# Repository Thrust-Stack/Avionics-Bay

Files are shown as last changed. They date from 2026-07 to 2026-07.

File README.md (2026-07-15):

# Avionics-Bay

Avionics bay for the **Thrust-Stack Tilt & Roll Control** high power model rocket:
an active canard-based **roll control** system, its sensor/telemetry stack, and
the airframe CAD.

> **Read this first — repository layout is unusual.**
> The `main` branch (which you are reading) currently contains **only the
> mechanical CAD** (`Tilt & Roll Control Project/`) and this README. **None of
> the firmware or control software is on `main`.** It lives on separate feature
> branches:
>
> | Branch | Contents |
> |--------|----------|
> | [`Controls`](../../tree/Controls) | Most complete software set — ESP32 firmware, roll-control laws, GPS/telemetry logging, LoRa telemetry, wiring reference |
> | [`Raspi`](../../tree/Raspi) | Raspberry Pi 5 camera capture + a copy of the control/GPS programs |
> | [`Meshtastic-Programs`](../../tree/Meshtastic-Programs) | Meshtastic serial send/receive experiments + wiring reference |
>
> File paths and code excerpts below are taken from the **`Controls`** branch
> unless noted. Nothing here has been merged into `main`.

---

## Table of Contents

1. [Project Overview](#1-project-overview)
2. [Hardware Architecture](#2-hardware-architecture)
   - [2.1 Components](#21-components)
   - [2.2 Buses and Wiring](#22-buses-and-wiring)
   - [2.3 Power System](#23-power-system)
   - [2.4 Wiring Diagram / Schematic (placeholder)](#24-wiring-diagram--schematic-placeholder)
   - [2.5 Documentation vs. firmware discrepancies](#25-documentation-vs-firmware-discrepancies)
3. [Software Architecture](#3-software-architecture)
   - [3.1 Data path](#31-data-path)
   - [3.2 Firmware / module reference](#32-firmware--module-reference)
   - [3.3 Control loop](#33-control-loop)
   - [3.4 Arming / safety state logic](#34-arming--safety-state-logic)
4. [Build and Flash Instructions](#4-build-and-flash-instructions)
5. [Repository Structure](#5-repository-structure)
6. [Safety Notes](#6-safety-notes)
7. [Status / Known Limitations](#7-status--known-limitations)

---

## 1. Project Overview

This repository is the avionics bay and control system for an active
**tilt/roll control** high power model rocket built by Thrust-Stack, intended
to fly on an **AeroTech H219** motor. The airframe carries movable **canards**
whose deflection generates a roll moment; the goal of the avionics bay is to
**hold the airframe near zero roll rate during boost and coast**, rather than
letting the rocket spin up on its own. On-board sensors measure angular rate,
acceleration, barometric altitude, and GPS position; a control law converts
roll-rate error into a commanded canard deflection.

> **What is actually implemented vs. the project name.** The folder is named
> *Tilt & Roll Control*, and the CAD includes both static fins and movable
> canards, but the **firmware and control laws in this repo implement roll
> control only** — a single signed deflection applied to two mirrored canards.
> Tilt (pitch/yaw) is *estimated* from the accelerometer and used as an input
> to the ground-test controller, but there is no thrust-vectoring or 4-axis fin
> control in the flashed firmware. See [§7](#7-status--known-limitations).
>
> The AeroTech H219 is the project's stated flight motor; the repository itself
> contains **no motor data or thrust curve** (the CAD `Fake Motor` parts are
> inert mass/fit models used for CFD and assembly, not the real motor).

---

## 2. Hardware Architecture

The wiring below reflects the **current physical harness** (I²C on GPIO 23/32,
direct-PWM canard servos, and a wired ESP32 ↔ Raspberry Pi 5 UART link). Where
older firmware or the historical branch wiring reference disagrees with this
harness, the conflict is called out in
[§2.5](#25-documentation-vs-firmware-discrepancies) — reconcile against the
sketch actually flashed before flight.

### 2.1 Components

| Role | Part | Interface | Address / pins / rate |
|---|---|---|---|
| Flight MCU / sensor bridge | **ESP32**, board `NodeMCU-32S` | — | USB serial @ **115200** to host |
| IMU (accel + gyro) | **MPU6050** (Adafruit driver) | I²C (SDA GPIO23 / SCL GPIO32) | **AD0 → GND** (nominal `0x68`) ¹; ±16 g accel, ±500 °/s gyro, 21 Hz DLPF; sampled @ **20 Hz** |
| Barometric altimeter | **BMP585** (Adafruit `BMP5xx`) | I²C (SDA GPIO23 / SCL GPIO32) | `BMP5XX_DEFAULT_ADDRESS` (**`0x46`** per code comment) ¹; 4× pressure OSR, IIR coeff 3; sampled @ **10 Hz** |
| GPS | **Adafruit Ultimate GPS V3** | UART (ESP32 `Serial2`) | **9600** baud, NMEA; GPS TX → GPIO16, GPS RX → GPIO17; powered from ESP32 3V3 |
| Roll actuators | **2 × canard servos** (wiring ref names *BMS-127WV+*) | Direct ESP32 PWM | **Canard 1 → GPIO26, Canard 2 → GPIO25**; neutral 90°; ±15° max deflection |
| Onboard computer | **Raspberry Pi 5** | UART to ESP32 | Pi GPIO14 (TX) → ESP32 **GPIO27** (RX); Pi GPIO15 (RX) ← ESP32 **GPIO33** (TX); common GND required |
| Telemetry radio (optional) | **Heltec WiFi LoRa 32 V4** (Semtech **SX1262**) | SPI + LoRa | 915 MHz, SF7, BW 125 kHz, CR 4/5, +14 dBm, 2 Hz |
| Ground station | Laptop running the Python stack | USB serial + UDP | — |

¹ With AD0 physically tied to GND the MPU6050 should respond at `0x68`, but the
`Controls`-branch firmware historically defined `MPU6050_ADDR = 0x69` with the
comment *"AD0 reads high on this board despite being wired to GND."* The old
wiring reference also listed the BMP585 at `0x47` in places. Confirm both
addresses with an I²C scanner on the current harness before flight.

> **PCA9685 removed from the harness.** Earlier revisions drove the canards
> through a PCA9685 16-channel PWM driver (I²C `0x40`, channels 12/13). The
> current wiring drives both servos **directly from ESP32 GPIO 25/26** and the
> PCA9685 is no longer part of the signal chain. If the flashed sketch still
> initializes a PCA9685, it does not match this harness — see
> [§2.5](#25-documentation-vs-firmware-discrepancies).

### 2.2 Buses and Wiring

Current harness, ESP32 as the hub:

```text
BMP585 ──┐
          ├── I²C (SDA GPIO23 / SCL GPIO32) ──► ESP32 ──USB serial 115200──► Laptop
MPU6050 ─┘   (MPU AD0 → GND)                     │
                                                  ├── UART2 (RX GPIO16 ◄─ GPS TX,
                                                  │          TX GPIO17 ─► GPS RX, 9600)
                                                  ├── GPIO26 ─► Canard 1 servo PWM
                                                  ├── GPIO25 ─► Canard 2 servo PWM
                                                  └── UART (RX GPIO27 ◄─ Pi GPIO14 TX,
                                                            TX GPIO33 ─► Pi GPIO15 RX)
                                                                 Raspberry Pi 5
                                                            (common GND with ESP32)
```

Pin-by-pin:

| Signal | From | To |
|---|---|-----|
| GPS VIN | ESP32 **3V3** | GPS VIN |
| GPS GND | ESP32 GND | GPS GND |
| GPS TX | GPS | ESP32 **GPIO16** (Serial2 RX) |
| GPS RX | GPS | ESP32 **GPIO17** (Serial2 TX) |
| I²C SDA (shared) | MPU6050 + BMP585 SDA | ESP32 **GPIO23** |
| I²C SCL (shared) | MPU6050 + BMP585 SCL | ESP32 **GPIO32** |
| MPU6050 AD0 | MPU6050 | ESP32 GND |
| Canard 1 servo PWM | ESP32 **GPIO26** | Servo 1 signal |
| Canard 2 servo PWM | ESP32 **GPIO25** | Servo 2 signal |
| Pi TX → ESP32 RX | Pi **GPIO14** | ESP32 **GPIO27** |
| Pi RX ← ESP32 TX | Pi **GPIO15** | ESP32 **GPIO33** |
| Pi GND | Pi | ESP32 GND (**common ground required**) |

- **I²C bus (shared):** MPU6050 and BMP585 share `SDA = GPIO23`,
  `SCL = GPIO32`, with unique addresses.
- **GPS:** UART on `Serial2` (GPIO16/17), 9600 baud; raw NMEA is forwarded to
  the host.
- **Actuators:** the two mirrored canards are driven by **direct ESP32 PWM** on
  GPIO26 (canard 1) and GPIO25 (canard 2). No external PWM driver.
- **Pi 5 link:** a dedicated UART now physically connects the ESP32
  (GPIO27 RX / GPIO33 TX) to the Pi's GPIO14/15, with grounds commoned. Verify
  which sketch/host program actually uses this link — the `Controls`-branch
  bridge historically streamed over **USB serial to a laptop**
  ([§2.5](#25-documentation-vs-firmware-discrepancies)).
- **Telemetry radio (separate board):** The Heltec V4 pinout is SPI
  (`SCK 9 / MISO 11 / MOSI 10 / NSS 8`), `DIO1 14`, `RST 12`, `BUSY 13`, plus
  RF front-end enable on `GPIO2`. It is an independent link, not wired into the
  ESP32 sensor bridge.

### 2.3 Power System

| Component | Voltage | Source |
|---|---|---|
| ESP32 | 5 V | USB or 5 V regulator |
| Raspberry Pi 5 | 5 V | USB-C PD or 5V-5A battery |
| GPS V3 / BMP585 / MPU6050 | 3.3 V | ESP32 `3V3` pin |
| Canard servos | 7.4 V 2S LiPo with a 2200 μF bulk cap — *the wiring reference also mentions a 5 V BEC; reconcile before flight* | Dedicated rail, **never** the ESP32 |

- Sensors and the GPS run off the ESP32's onboard 3.3 V regulator (AMS1117).
  Note this regulator has limited headroom with GPS + BMP585 + MPU6050 all on
  the 3V3 pin; watch for brownouts under load and consider a dedicated 3.3 V
  buck for the sensor rail.
- Servos must be powered from a **dedicated rail** (a 5 V BEC rated ≥5 A per the
  doc, 8–10 A recommended; or a 7.4 V 2S LiPo). The wiring reference is
  internally inconsistent about which — verify your servo voltage rating (2S is
  8.4 V fully charged) before connecting.
- **All grounds must be common:** ESP32, servo power rail, sensors, GPS, and Pi.
  The Pi ↔ ESP32 ground link is explicitly part of the harness (see §2.2).

### 2.4 Wiring Diagram / Schematic (placeholder)

> **No schematic or wiring image exists in the repository yet.** The pin table
> in §2.2 above is the current authoritative connection list. A proper
> KiCad/schematic capture or a labeled wiring photo should be added here:
>
> ```
> docs/wiring-diagram.png   <-- TODO: add schematic / harness diagram
> ```

### 2.5 Documentation vs. firmware discrepancies

The harness in §2.2 is the **current physical wiring**. The `Controls`-branch
firmware and the older branch wiring reference were written against earlier
revisions and may not match it. **Verify the flashed sketch against this table
before flight:**

| Topic | Current harness (§2.2) | Older firmware / wiring reference |
|---|---|---|
| I²C pins | SDA **GPIO23** / SCL **GPIO32** | Firmware: `Wire.begin(21, 22)` |
| Actuators | **2 canards, direct ESP32 PWM** on GPIO26 (canard 1) / GPIO25 (canard 2) | Firmware: 2 canards via **PCA9685** (I²C `0x40`) ch 12/13 @ 50 Hz; old wiring ref: 4 servos on GPIO 13/14/25/26 @ 250 Hz |
| PCA9685 | **Not in the harness** | Firmware initializes it; old wiring ref maps servos to ch 0–3 in one section, ch 12/13 in the firmware |
| MPU6050 address | AD0 → GND (nominal **`0x68`**) | Firmware: `0x69` (comment: "AD0 reads high on this board despite being wired to GND") — rescan on the current board |
| BMP585 address | `0x46` (code comment) | Old wiring ref: `0x47` in places; firmware error string separately mentions `0x47` |
| ESP32 ↔ Pi 5 UART | **Physically wired**: Pi GPIO14/15 ↔ ESP32 GPIO27/33, common GND | Firmware: link **not implemented** — the flashed bridge streams over USB serial to a laptop; old wiring ref described UART1 on GPIO 2/4 |

---

## 3. Software Architecture

### 3.1 Data path

The implemented system is a **hardware-in-the-loop link over USB + localhost
UDP**, not a self-contained onboard controller:

```text
[ESP32 bridge] --USB serial 115200--> [GPSReader.py]
      ^  ($IMU 20Hz, $ALT 10Hz, NMEA passthrough)   |
      |                                              | UDP 5761 (telemetry: $IMU/$ALT/$GPS)
      |                                              v
      |                                    [BasicRollControl.py  OR
      |                                     GroundRollControlTest.py]
      |                                              |
      +-------- serial <-- UDP 5760 (ROLL,<deg>) ----+
                (GPSReader relays UDP 5760 -> ESP32 serial)
```

- ESP32 emits `$IMU,ax,ay,az,gx,gy,gz` (accel m/s², **gyro rad/s** from the
  Adafruit driver) at 20 Hz, `$ALT,<agl_m>` (ground-zeroed barometric altitude)
  at 10 Hz, and passes GPS NMEA through unchanged.
- `GPSReader.py` logs everything to SQLite and re-broadcasts sensor packets on
  UDP `127.0.0.1:5761`. It relays inbound `ROLL,<deg>` commands from UDP
  `5760` straight to the ESP32 over the serial port it already holds.
- A controller listens on 5761, computes a deflection, and sends `ROLL,<deg>`
  to 5760. The ESP32 applies the same signed deflection to both canards.
- **Pi 5 UART:** the ESP32 ↔ Pi UART link (ESP32 GPIO27/33 ↔ Pi GPIO14/15) is
  now **physically wired** (§2.2), but the `Controls`-branch software path
  above still runs over USB serial to a laptop. Software support for the Pi
  link (on both the ESP32 sketch and a Pi-side reader) must be confirmed or
  added before it can replace the USB path.

### 3.2 Firmware / module reference

| File (branch) | Runs on | Responsibility |
|---|---|---|
| `Esp32 Programs/Esp32_sensor_bridge/Esp32_sensor_bridge.ino` (Controls) | ESP32 | Reads MPU6050 + BMP585 (I²C) and GPS (UART2); streams `$IMU`/`$ALT`/NMEA over USB; parses `ROLL,<deg>` and drives the canards. Zeroes ground pressure at boot (20-sample average). **Note:** the checked-in version drives the canards via PCA9685 and uses I²C on GPIO21/22 — it predates the direct-PWM / GPIO23-32 harness in §2.2. |
| `GPSReader.py` (Controls/Raspi) | Laptop | Auto-detects the ESP32 COM port; parses `$IMU`/`$ALT`/NMEA; logs to `logs/flight_*.db` (SQLite) and auto-exports `.xlsx`; UDP telemetry re-broadcast + command relay. |
| `Controls/Roll Control/BasicRollControl.py` (Controls) | Laptop | **Flight-intent** roll controller: Kalman-filtered roll rate, multi-sensor velocity fusion, velocity-scheduled gain, altitude/tilt/staleness safety gate. |
| `Controls/Roll Control/GroundRollControlTest.py` (Controls) | Laptop | **Bench/ground** controller: aggressive fixed gains, ±15° authority, roll-rate + tilt terms. Explicitly **bypasses altitude safety — not a flight controller.** |
| `export_to_excel.py` (Controls/Raspi) | Laptop | Converts a session `.db` into a formatted 3-sheet (GPS/IMU/ALT) Excel workbook. |
| `Communication/HeltecV4TelemetryTransmitter.ino` / `…Receiver.ino` (Controls) | 2× Heltec V4 | Point-to-point 20-byte LoRa telemetry (SX1262 via RadioLib) with CRC-16/CCITT and a packet counter for loss detection. **Transmitter payload is placeholder data** (`fillSensorData()` hardcodes example values). |
| `Communication/heltec_link_test.py` (Controls) | 2× laptops | tx/rx/compare link-quality test that reports delivered %, RSSI, SNR, and missing packet IDs. |
| `Communication/Sender.py` / `Reciever.py` (Controls/Meshtastic) | Laptop | Meshtastic serial send/receive experiments. `Sender.py` transmits **placeholder joke strings**, not telemetry. |
| `Camera/camera_capture.py` (Raspi) | Raspberry Pi 5 | Picamera2 H.264/MP4 video, periodic JPEGs, and full-res stills. Never raises on camera failure — isolated from the rest of the stack. |

### 3.3 Control loop

**`BasicRollControl.py` (flight-intent), ~100 Hz:**

1. Receive `$IMU`/`$ALT`/`$GPS` snapshots over UDP; convert gyro rad/s → deg/s.
2. Estimate roll rate with a scalar **Kalman filter** (`gyro_z` taken as roll
   axis).
3. Estimate vertical velocity with a **1-state Kalman velocity-fusion**
   estimator combining GPS vertical velocity, integrated accelerometer, and
   differentiated barometric altitude, with innovation gating.
4. **Gain scheduling:** below 0.1 m/s use nominal `KP`; above it, scale gain by
   `KP / (CANARD_ACCELERATION_COEFFICIENT · v²)` so control authority tracks
   dynamic pressure.
5. Command `fin = clamp(gain · (0 − roll_rate), ±7.5°)`, send `ROLL,<deg>`.
6. On exit / stale telemetry, command neutral (0°).

**`GroundRollControlTest.py` (bench), continuous:** fixed `ROLL_RATE_GAIN = 1.4`,
`TILT_GAIN = 2.0`, ±15° authority; `command = 1.4·roll_rate_error − 2.0·tilt_y`;
tilt estimated from the accelerometer (valid only for slow/ground motion).

**ESP32 `setCanards()`:** clamps to ±15°, applies the same signed deflection to
both canards around 90° neutral (plus per-canard trim constants, currently 0).
In the current harness the outputs are direct PWM on GPIO26/25 (§2.2); the
checked-in sketch still targets PCA9685 channels
([§2.5](#25-documentation-vs-firmware-discrepancies)).

### 3.4 Arming / safety state logic

There is **no hardware arm switch, insert-to-arm pin, or pyro interlock** in the
firmware. "Arming" is entirely **software gating** in the host controller:

- **`BasicRollControl.py`** runs a two-state machine:
  `CONTROL_ACTIVE` only when `control_is_allowed()` (altitude ≥ 0, |tilt_x| <
  90°, |tilt_y| < 90°) **and** telemetry is fresh (an IMU packet within 0.5 s);
  otherwise `IDLE` → **neutral command**. Loss of telemetry → neutral.
- **`GroundRollControlTest.py`** has only a freshness gate
  (`GROUND_TEST_ACTIVE` vs `STALE_TELEMETRY` → neutral) and **deliberately
  bypasses the altitude/tilt safety logic** — its own argparse help says *"do
  not use as flight controller."*
- **On the ESP32**, canards are parked at neutral (90°) at boot; the servos will
  physically move to neutral as soon as the board powers up.

---

## 4. Build and Flash Instructions

There is **no Makefile, PlatformIO project, or CMake** anywhere in the repo. The
firmware is Arduino sketches and the host code is plain Python scripts.

### 4.1 ESP32 sensor bridge (`Esp32_sensor_bridge.ino`)

- **Board:** `NodeMCU-32S` (ESP32) in the Arduino IDE / `arduino-cli`.
- **Libraries** (Library Manager, per the sketch header): Adafruit MPU6050,
  Adafruit BMP5xx, Adafruit Unified Sensor. (The Adafruit PWM Servo Driver
  Library was required by the PCA9685-era sketch; a direct-PWM build will use
  `ESP32Servo` or LEDC instead — match the sketch you flash.)
- Open `Esp32 Programs/Esp32_sensor_bridge/Esp32_sensor_bridge.ino`, select the
  board and port, and Upload.
- **Verify pins against §2.2 before flashing:** the checked-in sketch predates
  the current harness (I²C on 21/22, PCA9685 actuation). Update `Wire.begin()`
  to (23, 32) and the servo output path to direct PWM on GPIO26/25 — or rewire —
  before running the control loop.

### 4.2 Heltec V4 LoRa telemetry (`HeltecV4Telemetry*/…ino`)

- **Library:** RadioLib (Library Manager).
- Select the **exact Heltec WiFi LoRa 32 V4** board revision; attach the correct
  regional LoRa antenna **before powering** (there is a separate 2.4 GHz
  connector — do not confuse them).
- Flash the transmitter to the avionics board and the receiver to the ground
  board; open both serial monitors at 115200. For the transmitter's TX log lines
  over USB, compile with **USB CDC On Boot: Enabled**.

### 4.3 Host Python stack (laptop)

Dependencies are documented per-script; there is no single `requirements.txt`.
The only pinned file is `Communication/requirements-link-test.txt` (`pyserial`).

```bash
# GPS/telemetry logger + Excel export
pip install pyserial pynmea2 openpyxl
python GPSReader.py            # then, in another terminal:
python "Controls/Roll Control/BasicRollControl.py"       # or GroundRollControlTest.py
python export_to_excel.py     # convert the latest logs/*.db to .xlsx

# LoRa link-quality test (two computers)
py -m pip install -r Communication/requirements-link-test.txt
py Communication/heltec_link_test.py tx --port COM7 --duration 120 --output tx_report.json
py Communication/heltec_link_test.py rx --port COM9 --duration 120 --output rx_report.json
py Communication/heltec_link_test.py compare tx_report.json rx_report.json

# Meshtastic experiments
pip install meshtastic pypubsub
```

Use `--no-commands` on either controller to observe telemetry without moving
servos.

### 4.4 Raspberry Pi 5 camera (`camera_capture.py`, Raspi branch)

- **Picamera2 is installed via apt, not pip:** `sudo apt install -y
  python3-picamera2 ffmpeg`. If using a venv, create it with
  `--system-site-packages`.
- Verify with `rpicam-hello --list-cameras` (expect `imx708`), then:
  `python3 camera_capture.py --mode video --duration 30`.

---

## 5. Repository Structure

### `main` branch (this branch)

| Path | Purpose |
|---|---|
| `README.md` | This document. |
| `Tilt & Roll Control Project/` | SolidWorks CAD for the airframe and bay. |
| `Tilt & Roll Control Project/*.SLDPRT` | Parts: canards, airfoil fins, avionics bay plates (top/bottom), body tubes, nose cone, couplers, servo mount/attachment, bearings & mounts, camera mount, Pi Camera Module 3, fin jig, "fake" motor/bearing (fit models). |
| `Tilt & Roll Control Project/*.SLDASM` | Assemblies: `Rocket Assembly (1–3)`, `Camera + Mount`, `Static Fin + Lower Bearing Mount`. |
| `Tilt & Roll Control Project/CFD Model (3)/` | CFD variant of the assembly + a `.STEP` export. |

> `main` contains **no source code, build files, or wiring diagrams** — only CAD
> and this README.

### Software branches (not merged into `main`)

| Path (on `Controls` / `Raspi`) | Purpose |
|---|---|
| `Esp32 Programs/Esp32_sensor_bridge/` | ESP32 sensor-bridge + roll-actuation firmware. |
| `GPSReader.py`, `export_to_excel.py` | Host logger and Excel export. |
| `Controls/Roll Control/` | `BasicRollControl.py` (flight-intent), `GroundRollControlTest.py` (bench). |
| `Communication/` | Heltec LoRa sketches + `heltec_link_test.py` + `HELTEC_V4_TELEMETRY.md`; Meshtastic `Sender.py`/`Reciever.py`. |
| `Camera/` (Raspi) | `camera_capture.py` + camera README. |
| `logs/` | Captured session `.db`/`.xlsx` files. |
| `README.md` (branch) | Historical wiring reference — superseded by §2.2 of this document; see [§2.5](#25-documentation-vs-firmware-discrepancies) for its known conflicts. |

---

## 6. Safety Notes

> ⚠️ This is a **high power rocket**. Treat every step below as capable of
> causing injury or fire.

- **Motor / launch (AeroTech H219):** High power motors require appropriate
  certification (e.g., NAR/Tripoli), an approved launch site, and FAA/landowner
  compliance. The repository contains no ignition or launch-detect control code;
  **motor ignition is an external, irreversible action** — arm the igniter last,
  from a safe distance, per range rules.
- **Recovery / ejection charges are NOT handled by this repo.** There is no
  pyro, ejection-charge, or deployment code anywhere in the firmware. If the
  airframe uses ejection charges or a separate commercial flight computer for
  recovery, that system is **out of scope here** and must be armed and verified
  independently. Do not assume this avionics bay provides recovery.
- **Servos move on power-up.** The ESP32 drives both canards to neutral the
  instant it boots. **Keep hands and tools clear of the canards** whenever the
  bay is powered.
- **Never power the servos from the ESP32.** Use the dedicated servo rail (5 V
  BEC or 2S LiPo per the wiring reference). Verify servo voltage rating against a
  fully charged 2S (8.4 V) before connecting.
- **LiPo handling:** charge/store/transport per standard LiPo safety; a 2S servo
  pack at 8.4 V can source high current into a fault.
- **Ground testing:** `GroundRollControlTest.py` uses **aggressive gains and the
  full ±15° deflection and bypasses altitude safety.** Bench-test with the
  airframe restrained and clear of people; it is not a flight controller.
- **Verify pins and addresses before flight:** the checked-in firmware and the
  current harness disagree on I²C pins, actuator wiring, and possibly I²C
  addresses ([§2.5](#25-documentation-vs-firmware-discrepancies)). Confirm the
  MPU6050 and BMP585 with an I²C scanner on GPIO23/32 and sweep both servos on
  GPIO26/25 before installing the bay.

---

## 7. Status / Known Limitations

Grounded in the current code and comments:

- **Software is unmerged and split across branches.** `main` has no firmware;
  `Controls`, `Raspi`, and `Meshtastic-Programs` are not integrated with each
  other.
- **Roll only.** Despite the "Tilt & Roll" name and the 4-fin/canard CAD, only
  **2-canard roll control** is implemented. There is no thrust-vectoring or
  independent 4-fin control in firmware.
- **No flight validation in the repo.** The controllers are labeled "basic" and
  "ground test"; session logs exist under `logs/`, but there is **no evidence of
  a validated powered flight**, and no test report characterizing performance.
- **Checked-in firmware lags the current harness.** The harness now uses I²C on
  GPIO23/32, direct servo PWM on GPIO26/25 (no PCA9685), and a wired ESP32↔Pi
  UART (GPIO27/33 ↔ Pi GPIO14/15) — the `Controls`-branch sketch still
  initializes I²C on 21/22 and drives a PCA9685
  ([§2.5](#25-documentation-vs-firmware-discrepancies)). Update and re-verify
  before flight.
- **Pi 5 UART link is wired but its software path is unconfirmed.** The
  physical UART now exists (§2.2), but the checked-in bridge streams to a
  **laptop over USB**; ESP32-side and Pi-side software for the UART link must
  be confirmed or written.
- **LoRa telemetry sends placeholder data.** `HeltecV4TelemetryTransmitter.ino`'s
  `fillSensorData()` hardcodes example altitude/battery/temp/GPS values —
  *"Replace these example values with real sensor reads."* It is not yet wired to
  the sensor bridge.
- **Meshtastic scripts are experiments.** `Sender.py` transmits placeholder joke
  strings; `Reciever.py`'s `PORT` is unset (`"xxxx"`).
- **Uncalibrated actuator trims.** `CANARD1_TRIM` / `CANARD2_TRIM` are `0.0`
  with a "tune until neutral" comment.
- **Gyro-unit assumptions.** Comments disagree on whether gyro is logged in
  rad/s or deg/s; the controllers default to `rad/s` and assume `gyro_z` is the
  roll axis for the current wiring. Confirm on hardware.
- **No build system / no schematic image.** Arduino sketches + loose Python
  scripts; no Makefile/PlatformIO; no wiring diagram or schematic file.

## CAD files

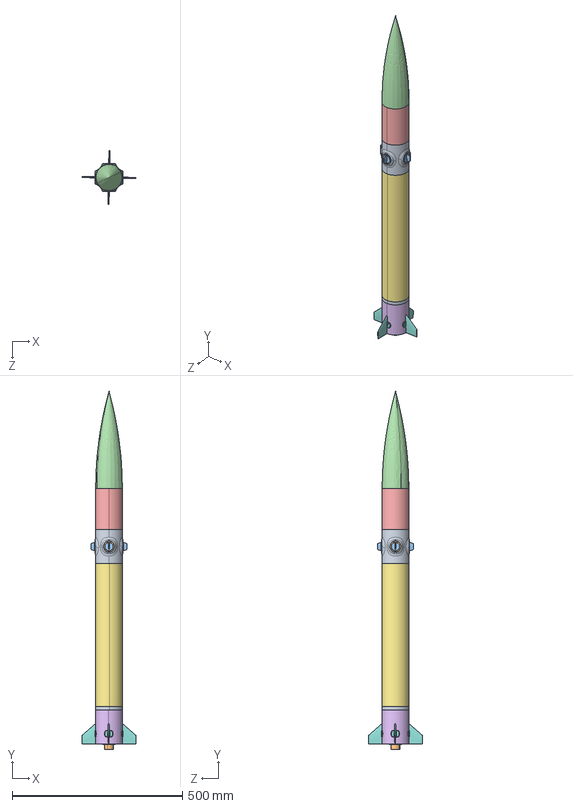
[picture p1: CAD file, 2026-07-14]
Tilt & Roll Control Project/CFD Model (3)/Rocket Assembly (3) (CFD).STEP
158.6 x 1052.1 x 158.6 mm
Servo Fin Can (3) (CFD)
Small Bearing (3) (CFD) x 4
Airfoil Canard (4) (CFD) x 4
Nose Cone (CFD)
Upper Body Tube (3) (CFD)
Static Fin Can (3) (CFD)
Lower Body Tube (3) (CFD)
Airfoil Fin (CFD) x 4
Lower Bearing Mount (2) (CFD)
Fake Motor (CFD)

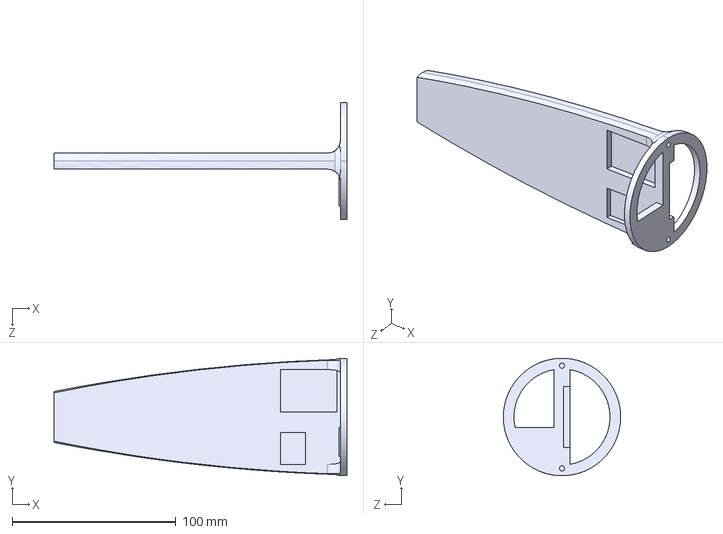
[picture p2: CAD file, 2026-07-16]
Tilt & Roll Control Project/26.07.10 Avionics Bay Plate (Top Half).STEP
178.7 x 71.6 x 71.6 mm

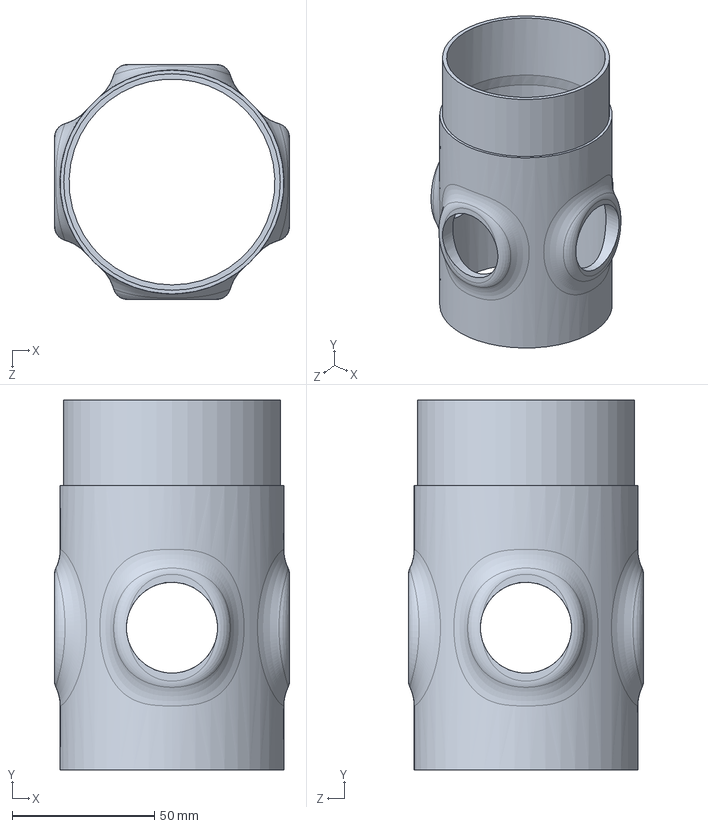
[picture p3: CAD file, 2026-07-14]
Tilt & Roll Control Project/CFD Model (3)/Servo Fin Can (3) (CFD).SLDPRT
82.6 x 130.0 x 82.6 mm

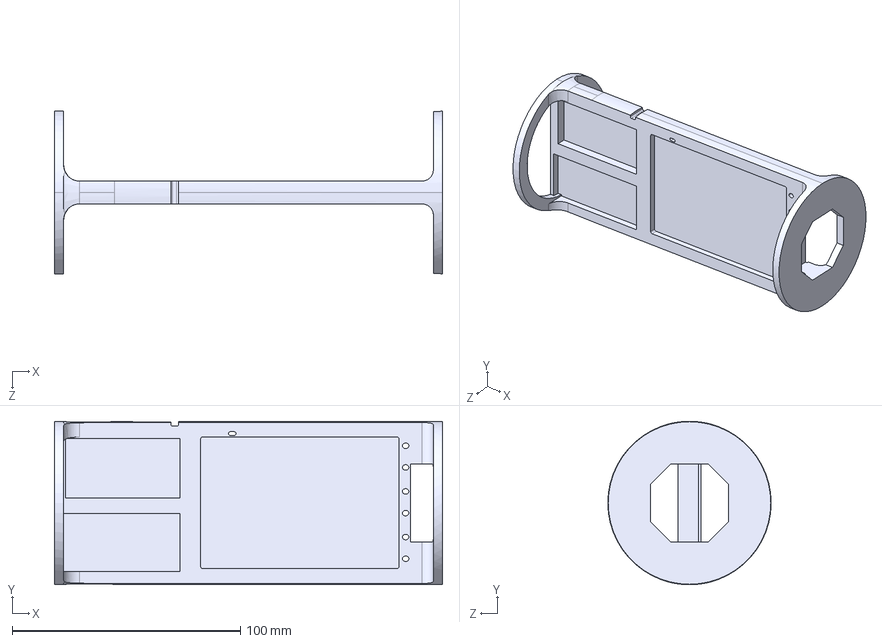
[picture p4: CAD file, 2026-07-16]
Tilt & Roll Control Project/26.07.13 Avionics Bay Plate (Bottom Half).STEP
170.0 x 71.6 x 71.6 mm

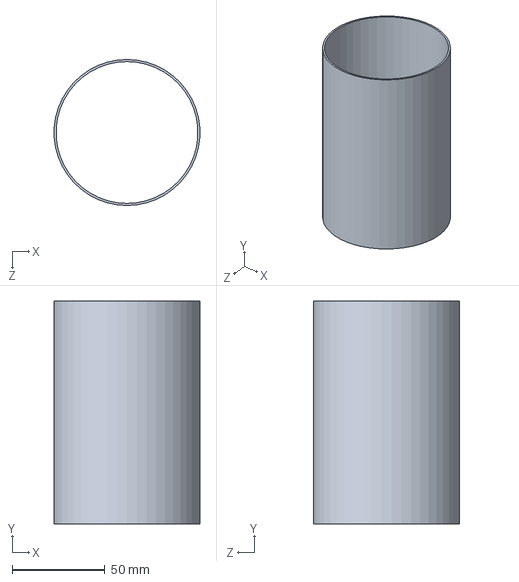
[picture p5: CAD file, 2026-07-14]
Tilt & Roll Control Project/CFD Model (3)/Upper Body Tube (3) (CFD).SLDPRT
78.4 x 120.0 x 78.6 mm

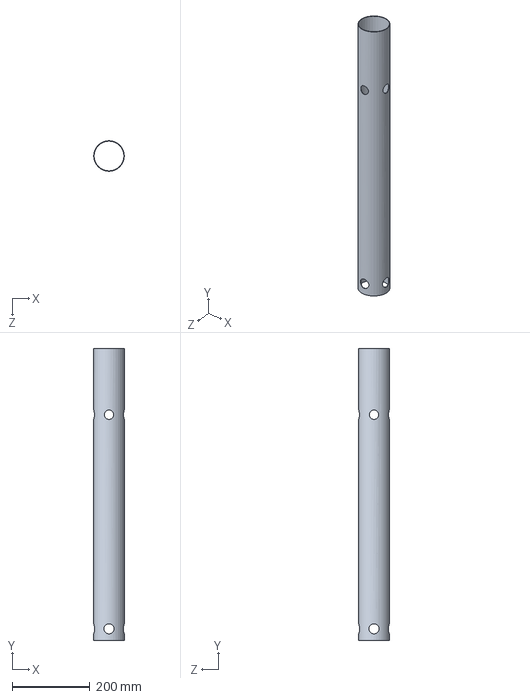
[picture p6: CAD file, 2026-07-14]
Tilt & Roll Control Project/Body Tube (1).SLDPRT
78.6 x 750.0 x 78.6 mm

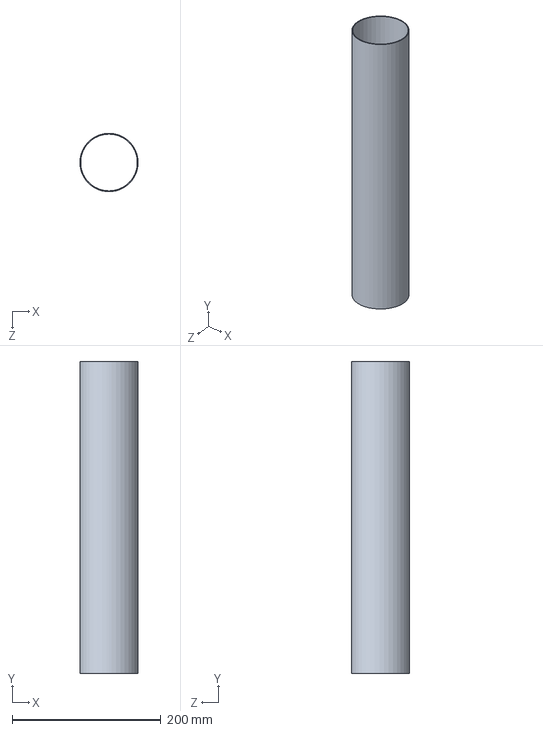
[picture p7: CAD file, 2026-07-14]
Tilt & Roll Control Project/CFD Model (3)/Lower Body Tube (3) (CFD).SLDPRT
78.5 x 420.0 x 78.6 mm

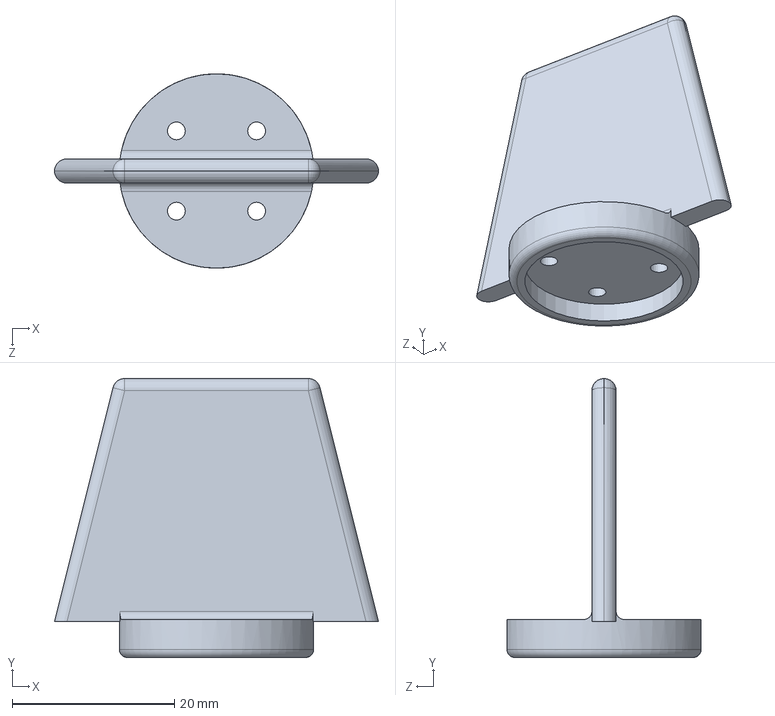
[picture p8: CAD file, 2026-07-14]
Tilt & Roll Control Project/Canard.SLDPRT
40.0 x 34.5 x 24.0 mm

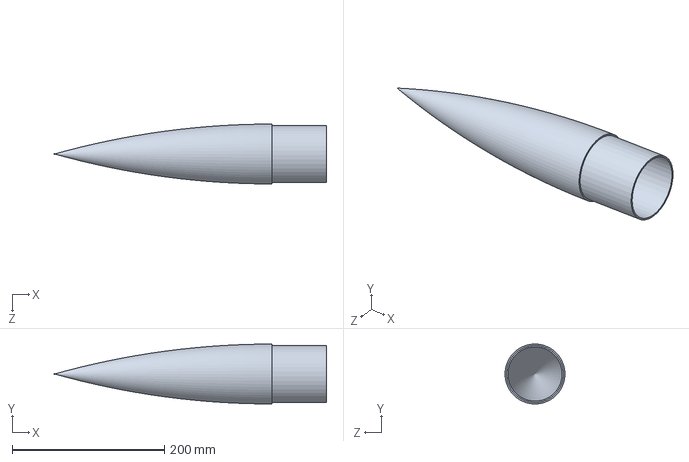
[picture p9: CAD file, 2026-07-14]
Tilt & Roll Control Project/CFD Model (3)/Nose Cone (CFD).SLDPRT
357.1 x 78.7 x 78.7 mm

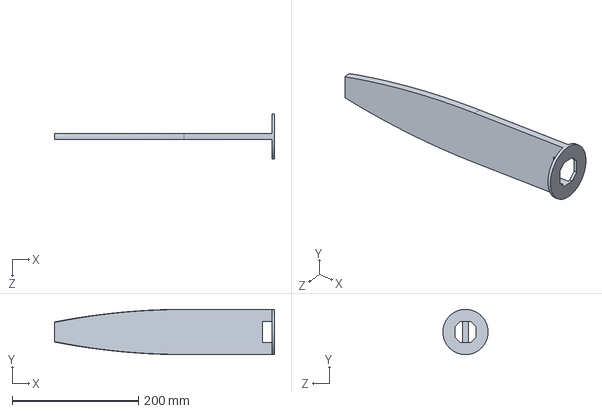
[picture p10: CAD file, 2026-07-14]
Tilt & Roll Control Project/Avionics Bay Plate.SLDPRT
348.7 x 71.9 x 71.9 mm

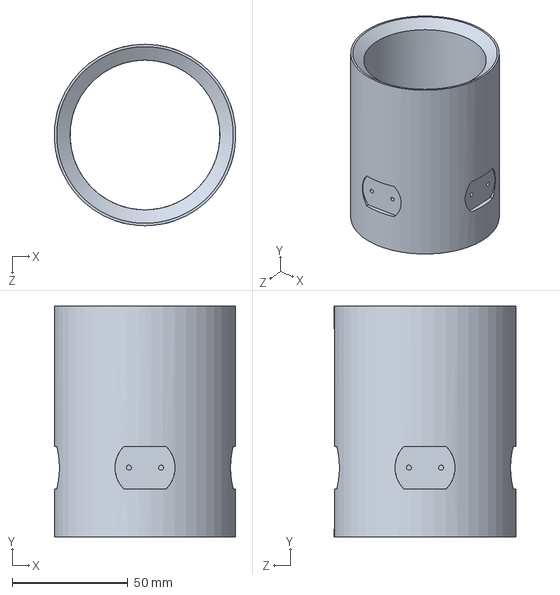
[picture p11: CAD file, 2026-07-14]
Tilt & Roll Control Project/CFD Model (3)/Static Fin Can (3) (CFD).SLDPRT
78.6 x 100.0 x 78.6 mm

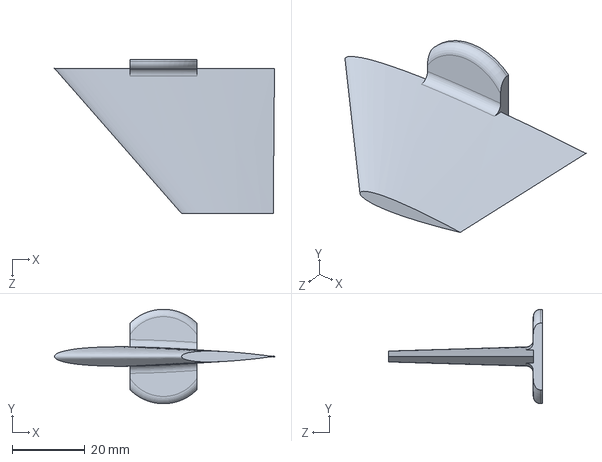
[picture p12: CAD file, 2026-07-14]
Tilt & Roll Control Project/CFD Model (3)/Airfoil Fin (CFD).SLDPRT
60.6 x 26.0 x 42.5 mm

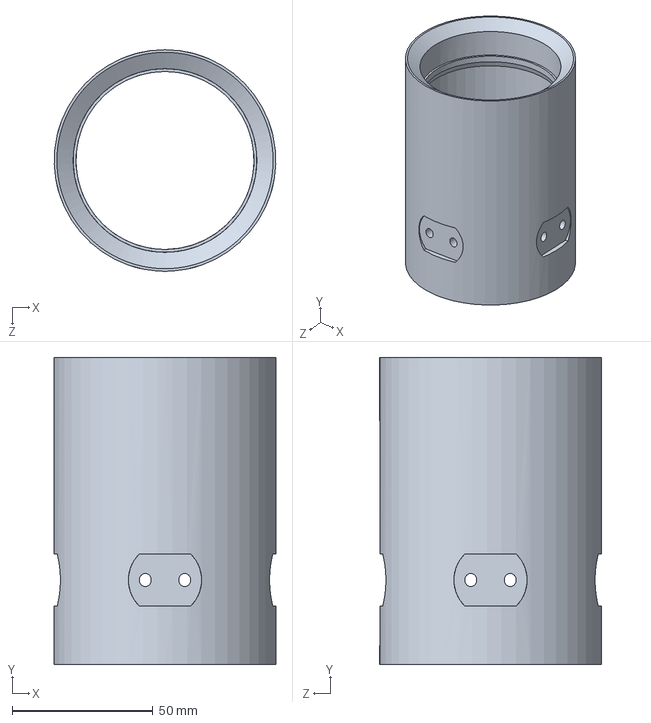
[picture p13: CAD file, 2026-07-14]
Tilt & Roll Control Project/Static Fin Can (3).SLDPRT
78.7 x 109.0 x 78.7 mm

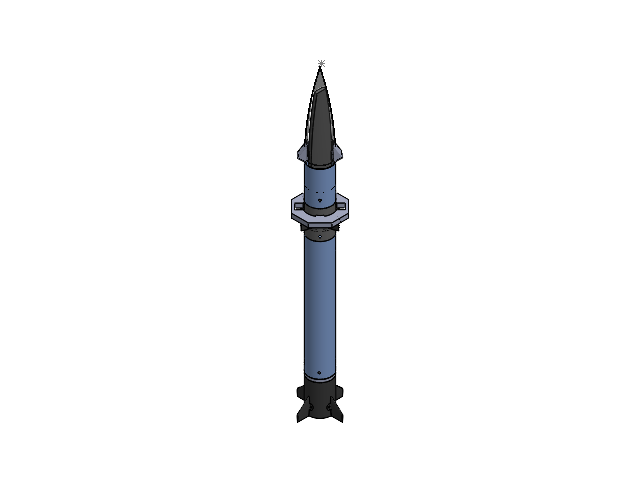
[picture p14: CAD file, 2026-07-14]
Tilt & Roll Control Project/Rocket Assembly (3).SLDASM
Servo Fin Can (3)
Small Bearing (3) x 4
Airfoil Canard (3) x 4
Servo Attachment x 4
Servo Mount
Avionics Bay Plate
Nose Cone
Upper Body Tube (3)
Static Fin Can (3)
Lower Body Tube (3)
Airfoil Fin x 4
Lower Bearing Mount (2)
Fake Bearing (2) x 2
Fake Motor
Coupler (4)
Camera Mount x 2
Fin Jig

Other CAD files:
Tilt & Roll Control Project/Rocket Assembly (1).SLDASM
Tilt & Roll Control Project/Static Fin + Lower Bearing Mount.SLDASM
Tilt & Roll Control Project/Camera + Mount.SLDASM
Tilt & Roll Control Project/Rocket Assembly (2).SLDASM
Tilt & Roll Control Project/Airfoil Canard (3).SLDPRT
Tilt & Roll Control Project/Airfoil Canard (4).SLDPRT
Tilt & Roll Control Project/Airfoil Canard.SLDPRT
Tilt & Roll Control Project/Airfoil Fin.SLDPRT
Tilt & Roll Control Project/Avionics Bay Plate (Bottom).SLDPRT
Tilt & Roll Control Project/Avionics Bay Plate (Top).SLDPRT
Tilt & Roll Control Project/CFD Model (3)/Airfoil Canard (3) (CFD).SLDPRT
Tilt & Roll Control Project/CFD Model (3)/Airfoil Canard (4) (CFD).SLDPRT
Tilt & Roll Control Project/CFD Model (3)/Airfoil Canard (CFD).SLDPRT
Tilt & Roll Control Project/CFD Model (3)/Fake Motor (CFD).SLDPRT
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

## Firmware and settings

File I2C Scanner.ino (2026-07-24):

/*
 * I2C_Scanner — ESP32 bus diagnostic
 * SDA -> GPIO 23, SCL -> GPIO 32 (same as Esp32_sensor_bridge.ino)
 * Open Serial Monitor at 115200.
 * Expected on a healthy bus: 0x69 (MPU6050), 0x46 (BMP585)
 */

#include <Wire.h>

#define I2C_SDA_PIN  23
#define I2C_SCL_PIN  32

void setup() {
  Serial.begin(115200);
  delay(300);
  Wire.begin(I2C_SDA_PIN, I2C_SCL_PIN);
  Wire.setClock(100000);  // 100 kHz — slow/robust for diagnosis
  Serial.println();
  Serial.println("I2C scanner — SDA=23, SCL=32");
  Serial.println("Expecting 0x69 (MPU6050) and 0x46 (BMP585).");
}

void loop() {
  int found = 0;
  Serial.println("Scanning...");
  for (uint8_t addr = 1; addr < 127; addr++) {
    Wire.beginTransmission(addr);
    uint8_t error = Wire.endTransmission();
    if (error == 0) {
      Serial.printf("  device found at 0x%02X\n", addr);
      found++;
    } else if (error == 4) {
      Serial.printf("  unknown error at 0x%02X\n", addr);
    }
  }
  if (found == 0) {
    Serial.println("  NONE found — bus is dead (check power / wiring / pull-ups).");
  } else {
    Serial.printf("  %d device(s) found.\n", found);
  }
  Serial.println();
  delay(1000);
}

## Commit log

2026-07-14 Add comprehensive README documenting avionics bay hardware and software
    Document the tilt/roll control avionics bay: hardware architecture (ESP32 sensor bridge, MPU6050, BMP585, GPS V3, PCA9685, canard servos, Heltec V4 LoRa, Pi 5 camera), the roll-control software path,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
2026-07-15 Update wiring references and power requirements in README
2026-07-15 Revise hardware architecture and wiring details
    Updated hardware architecture section with current wiring details, clarified component interfaces, and removed references to PCA9685. Added notes on discrepancies between documentation and firmware.
2026-07-24 Add I2C scanner for ESP32 bus diagnostics
    This code implements an I2C scanner for the ESP32, allowing users to detect devices on the I2C bus. It initializes the I2C communication and scans for devices, printing their addresses to the Serial 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
